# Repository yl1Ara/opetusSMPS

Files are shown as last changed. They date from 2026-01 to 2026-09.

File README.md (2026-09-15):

# opetUSMPS

The active instrument and inversion implementation is `V09_BipolarProto`. The hardware GUI runs on an instrument Raspberry Pi; online inversion is designed to run on a separate analysis computer. See `V09_BipolarProto/deploy/README.md` for installation and update procedures.

## Hardware profiles

- Bipolar systems use the SPI DAC, can scan both voltage polarities, and may enable the Pico inlet valve for Ntot measurements.
- Monopolar Spellman systems use positive scan points only, do not initialize the bipolar SPI DAC, and force Ntot valve measurements off.
- The verified `MPS` monopolar wiring uses the CPC on `/dev/serial0` (GPIO14/15) and Spellman on `/dev/ttyAMA3` (GPIO4/5 with `dtoverlay=uart3`).
- The hardware GUI requires the installed Hauke DMA length before initialization. `MPS` uses the 0.11 m DMA; existing installations retain the 0.28 m default unless configured otherwise. Each scan records its DMA length and radii for inversion.

## Porting older systems

Do not copy old GUI files over a deployment checkout. Commit reviewed changes, update through Git, and preserve settings/logs in the configured state directory so `dmps update` can require a clean fast-forward checkout.

Completed V09 scan CSVs include `scan_complete` and `expected_scan_points`. The inversion viewer rejects interrupted or time-window-truncated scans carrying this metadata, reports what it skipped, and continues processing other valid scans. It also isolates malformed files and individual range inversion failures instead of requiring operators to remove them manually.

Scans collected on a 0.11 m DMA while the controller was still configured for 0.28 m used incorrect classification voltages and should not be treated as correctly sized data. New scan files carry explicit geometry so this mismatch is detectable going forward.

Counting uncertainty is not `sqrt(cpc_count)` because `cpc_count` contains concentration in cm-3, not raw events. V09 converts concentration to effective counts using the configured CPC sample flow and each row's response/counting interval, applies Poisson `sqrt(N)` noise, and linearly propagates one-standard-deviation uncertainty through the active NNLS solution. Saved outputs include per-bin `heatmap_1sigma_*.csv` files and `Ntot_*_1sigma` columns. Verify CPC flow and counting-interval settings when porting this logic to older instruments.

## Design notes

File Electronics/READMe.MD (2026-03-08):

# [Interactive BOM](https://yl1ara.github.io/opetusSMPS/)

# Shopping lists and sites
components per pcb: https://www.digikey.fi/en/mylists/list/RQZPBNJORH

cables and extras: https://www.digikey.fi/en/mylists/list/IEEER25KGX

ACDC 24V 150W: https://www.mouser.fi/ProductDetail/XP-Power/AHM150PS24?qs=w%2Fv1CP2dgqrkrRjfQac7fA%3D%3D

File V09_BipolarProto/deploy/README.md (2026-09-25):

# Customer deployment

This deployment keeps all source files in one SSH-cloned monorepo checkout, but runs only the hardware GUI on an instrument Raspberry Pi:

- Hardware GUI: `gui.py`, systemd `tdmps@USER.service`, localhost port 5006 by default
- Online inversion files remain available for deployment on a separate analysis computer; they are not started on the Pi.

The hardware service restarts after process failures so its web interface remains available. Restarting the web process does not automatically initialize hardware or resume a scan. The server binds only to localhost and accepts only its configured exact websocket origin; wildcards are not used.

The templated hardware unit conflicts with the legacy `tdmps.service`, checks that the configured panel port is free before touching hardware, and rate-limits failed starts. Installation disables inactive legacy service names. If a legacy service is active, `dmps start`, `dmps restart`, and `dmps update` fail closed until it is stopped and disabled.

## SSH deploy key

Create a key on the customer system and leave its passphrase empty for unattended `git fetch`:

```bash
ssh-keygen -t ed25519 -f ~/.ssh/opetus_smps_deploy -C "customer-system-name deploy"
cat ~/.ssh/opetus_smps_deploy.pub
```

Add the public key to the repository as a read-only GitHub deploy key. Configure SSH to use it:

```sshconfig
Host github.com-opetus-smps
    HostName github.com
    User git
    IdentityFile ~/.ssh/opetus_smps_deploy
    IdentitiesOnly yes
```

Verify host identity and access interactively before installation:

```bash
ssh -T git@github.com-opetus-smps
```

## Clone and install

Clone the repository, not `V09_BipolarProto` by itself. The installer verifies this layout:

```text
<repository-root>/V09_BipolarProto
```

```bash
git clone git@github.com-opetus-smps:OWNER/opetusSMPS.git ~/opetusSMPS
cd ~/opetusSMPS/V09_BipolarProto
```

Install `uv` if it is not already available, then install with the system's exact Tailscale MagicDNS name. Origins contain only `host[:port]`, never `https://`, a path, or `*`:

```bash
curl -LsSf https://astral.sh/uv/install.sh | sh
deploy/install-services.sh --origin customer-host.tailnet-name.ts.net
```

Use `--port 5008` when an installation should use a non-default local Panel port. The systemd port guard, Panel launcher, health command, and Tailscale proxy all read the resulting `DMPS_PANEL_PORT` setting.

By default, runtime settings and logs remain under `V09_BipolarProto`. To preserve an existing absolute collection path while running code from a clean clone, pass an existing writable state directory:

```bash
deploy/install-services.sh --origin customer-host.tailnet-name.ts.net --state-dir /home/pi/Desktop/TDMPS
```

The services then load code and dependencies from the Git checkout but retain `settings.json`, `settings_inversion.json`, `logs/`, and viewer state under the state directory.

## Bipolar and monopolar installations

The bipolar installation uses the SPI DAC and may use the Pico inlet valve for Ntot measurements. Keep SPI enabled, select `Bipolar DAC`, and enable the Ntot valve only when that valve is physically installed.

The monopolar installation uses only positive scan points, does not use the bipolar SPI DAC, and never uses the Ntot valve. Disable SPI and enable the CPC and Spellman UARTs in `/boot/firmware/config.txt`:

```ini
## Monopolar MPS
#dtparam=spi=on
enable_uart=1
dtoverlay=disable-bt-pi5
dtoverlay=uart3
```

After rebooting, verify the serial devices before starting the GUI:

```bash
ls -l /dev/serial* /dev/ttyAMA* /dev/ttyS*
```

The verified `MPS` monopolar installation uses `/dev/serial0 -> /dev/ttyS0` on GPIO14/15 for the CPC and `/dev/ttyAMA3` on GPIO4/5 for the Spellman supply. Set `cpc_com_port` to `/dev/serial0`, `spellman_port` to `/dev/ttyAMA3`, `hv_source` to `Monopolar Spellman`, and the Hauke DMA length to `0.11 m` before initializing hardware. Selecting that source forces positive-only scans and disables Ntot controls in the GUI. Other installations retain the `0.28 m` DMA default unless explicitly changed.

After changing overlays, reboot and confirm GPIO4/5 report `TXD3`/`RXD3`. Device aliases can vary with firmware, so verify the actual devices instead of assuming `/dev/serial1` exists.

The installer acquires the instrument maintenance lock and refuses a busy or unverifiable running service before changing dependencies. It creates `.venv`, synchronizes locked application dependencies plus Raspberry Pi hardware dependencies, syntax-checks only the instrument application and hardware modules, installs `dmps`, enables only the hardware service, and verifies both its localhost endpoint and fresh process-matched `health.json` heartbeat. Before Panel starts, a bipolar installation writes calibrated midpoint code `32705` to its DAC; monopolar installations skip that startup action because SPI is disabled. Inversion code is not executed on the instrument.

## Operations and updates

```bash
dmps status
dmps health
dmps system-health
dmps diagnose-reboot
dmps update
```

`dmps update` operates on the complete monorepo. It acquires an exclusive maintenance lock, refuses a dirty tree or non-fast-forward pull, and reads a fresh `health.json` whose PID must match systemd's current process; it never opens a Panel session to determine whether measurement is idle. Measurement, initialization, tuning, and calibration hold shared maintenance leases, so they cannot begin or remain active during an update. If state cannot be verified, the update fails closed. After its final idle check, it stops the hardware service before changing the checkout or environment, runs dependency synchronization and Python syntax checks, installs runtime files, starts the service if it was previously active, and requires the new PID's localhost endpoint and heartbeat to pass. A failed update leaves the service stopped rather than running mixed old and new files. Do not copy tracked source files into an installed checkout: publish changes to GitHub, keep runtime files under the configured state directory, and use `dmps update` so the checkout remains clean.

Stop a measurement in the GUI and confirm it is idle before updating. Do not schedule `dmps update` from cron or a systemd timer. Do not manually run a second hardware GUI beside `tdmps@USER.service`.

Service logs are available with `dmps log`. Installation overrides Raspberry Pi OS's volatile-journal default and retains up to 200 MB or three months of system journals across reboots. The independent `tdmps-health-log@USER.service` fsyncs CPU temperature and frequency, Raspberry Pi throttling history, uptime, load, memory, boot identity, and Tailscale version/state every minute under `logs/system/`; `dmps system-health` shows its latest records. After an unexplained reboot or outage, `dmps diagnose-reboot` prints those records alongside boot history, watchdog policy, current Pi throttling flags, current and previous boot power/reset kernel messages, and retained previous-boot TDMPS service logs. `dmps events` shows the latest persistent JSONL runtime events from `logs/runtime/`, including panel sessions, measurement transitions, one-minute hardware heartbeats, scan QC, failures, and shutdown results. The existing `tdmps@USER.service` name is retained for compatibility.

Stopping the service first invokes the application's idempotent safe shutdown. After the process exits, `ExecStopPost` independently attempts to command the inlet valve off, both HV outputs safe, and the blower DAC to zero, regardless of the currently saved profile. Missing hardware is reported but does not prevent the remaining safing attempts. This second layer never runs alongside the application.

## Tailscale exposure

The hardware service remains localhost-only. To expose it to the tailnet, install and authenticate Tailscale, then enable the supplied proxy unit:

```bash
sudo tailscale up
sudo systemctl enable --now "tdmps-serve@$(whoami).service"
tailscale serve status
dmps url
```

The route is:

```text
https://customer-host.tailnet-name.ts.net/gui
```

Use Tailscale ACLs/grants to limit customer access. Do not open the local Panel port in the host firewall and do not bind Panel to `0.0.0.0`.

## One-time migration from the copied TDMPS directory

Older systems may have `/home/pi/Desktop/TDMPS` as a standalone, dirty checkout. Do not run `git pull` there and do not delete it. Stop measurement and zero HV in the GUI first, then create the clean monorepo clone described above. Preserve local state before replacing the legacy service:

```bash
mkdir -p ~/opetusSMPS/V09_BipolarProto/logs
rsync -a ~/Desktop/TDMPS/logs/ ~/opetusSMPS/V09_BipolarProto/logs/
cp ~/Desktop/TDMPS/settings.json ~/opetusSMPS/V09_BipolarProto/settings.json
cp ~/Desktop/TDMPS/settings_inversion.json ~/opetusSMPS/V09_BipolarProto/settings_inversion.json
sudo systemctl disable --now tdmps.service
cd ~/opetusSMPS/V09_BipolarProto
deploy/install-services.sh --origin "$(tailscale status --json | python3 -c 'import json,sys; print(json.load(sys.stdin)["Self"]["DNSName"].rstrip("."))')"
```

The installer intentionally refuses to proceed while the legacy service is active, preventing two hardware controllers from binding the same port or opening the same devices. Keep the old directory as a backup until the new main GUI, online viewer, settings, and historical logs have been verified.

The repository no longer tracks Python bytecode. Commit the accompanying `__pycache__` deletions and `.gitignore` update before cloning customer systems; otherwise imported bytecode can make future pulls dirty.

## Online inversion computer

Run inversion on a separate analysis computer, not on the instrument Pi. The repository includes `online_inversion_viewer.py`, `DMPS_inversion_gui/`, and `run_online_inversion_viewer.sh`. On the analysis computer:

```bash
cd ~/opetusSMPS/V09_BipolarProto
./run_online_inversion_viewer.sh
```

Set `ONLINE_VIEWER_ORIGIN=analysis-host.example:5007` when accessing it through another exact hostname. The launcher binds only to localhost by default; use a separate authenticated proxy or SSH forwarding for remote access.

On the CSC analysis host, install the tracked service helper after cloning the repository:

```bash
cd /home/ubuntu/opetusSMPS/V09_BipolarProto
sudo install -o root -g root -m 0755 deploy/inversion /usr/local/bin/inversion
sudo install -o root -g root -m 0644 deploy/inversion-completion.bash /etc/bash_completion.d/inversion
```

The production defaults are service `opetus-panel.service`, checkout
`/home/ubuntu/opetusSMPS/V09_BipolarProto`, and local health URL
`http://127.0.0.1:5008/online_inversion_viewer`. They can be overridden with
`INVERSION_SERVICE`, `INVERSION_APP_DIR`, and `INVERSION_HEALTH_URL`.

Use `inversion status`, `inversion health`, and `inversion tail` for routine
operation. `inversion update` refuses a dirty, detached, locally advanced, or
diverged checkout. It fetches and fast-forwards only from `origin/main`, runs a
locked dependency sync and Python/shell syntax checks, refreshes the helper,
and health-checks the restarted viewer. A stopped viewer remains stopped.

There is no reliable external signal for all per-session inversion jobs. When
the viewer is active, update therefore requires an interactive `UPDATE`
confirmation after all users have been notified and all jobs have finished.
Do not automate this command. It stops the viewer before changing source or
dependencies. A failed validation leaves it stopped; correct the problem,
rerun `inversion update`, then use `inversion start`. The Pi-specific
measurement-idle check does not protect online inversion work.

### CSC instrument data pull

The CSC `sync-dmps.timer` runs `/usr/local/bin/sync-dmps` as `ubuntu` every
30 minutes. The tracked script pulls `/home/pi/Desktop/TDMPS/logs/` from
`pi@varjo-dmps` into `/home/ubuntu/dmps/logs/` without deleting CSC files.
It uses `/home/ubuntu/.ssh/raspberrypi_sync` and the Pi's already-verified
`raspberrypi` SSH host-key entry (via `HostKeyAlias`). To install and check it
on CSC:

```bash
cd ~/opetusSMPS/V09_BipolarProto
sudo install -o root -g root -m 0755 deploy/sync-dmps /usr/local/bin/sync-dmps
sync-dmps --dry-run
sudo systemctl start sync-dmps.service
systemctl status sync-dmps.service --no-pager
systemctl list-timers sync-dmps.timer --no-pager
```

The first successful run may copy a backlog of scans. `journalctl -u
sync-dmps.service` shows the transfer summary or an SSH/rsync error.

The separate SMEAR III monopolar Pi (`pi@mps`) writes to
`/home/pi/opetusSMPS/V09_BipolarProto/logs/`. Its data belongs under
`/home/ubuntu/mps/logs/` on CSC, not in the bipolar `dmps` tree. Once CSC
can SSH to `pi@mps` without an interactive Tailscale check, install and
enable the independent MPS job:

```bash
cd ~/opetusSMPS/V09_BipolarProto
sudo install -o root -g root -m 0755 deploy/sync-mps /usr/local/bin/sync-mps
sudo install -o root -g root -m 0644 deploy/sync-mps.service /etc/systemd/system/sync-mps.service
sudo install -o root -g root -m 0644 deploy/sync-mps.timer /etc/systemd/system/sync-mps.timer
sync-mps --dry-run
sudo systemctl daemon-reload
sudo systemctl enable --now sync-mps.timer
sudo systemctl start sync-mps.service
systemctl status sync-mps.service --no-pager
```

If CSC gets a Tailscale SSH web-approval prompt, arrange noninteractive
access for this host in the tailnet policy before enabling the timer; an
interactive approval alone will not make unattended sync reliable.

### University SMB data through the desktop

The university SMB share is mounted on the local desktop using eduVPN's
**Split-tunnel** profile. CSC does not need eduVPN: a local user timer stages
only `*.scan` from UFSMPS 2026 and `*.scan`/`*.sum` from SMPS dated June 2026
onward, then pushes completed files to CSC over the existing SSH connection.
The local stage is `~/.local/share/opetusSMPS/university/2026/{ufsmps,smps}`;
CSC receives `/home/ubuntu/university/2026/{ufsmps,smps}`. No SMB login or
VPN configuration is copied to CSC, and no source or CSC files are deleted.

On the desktop, while logged in with eduVPN connected and `h527` mounted in
the file manager:

```bash
cd ~/Desktop/Projects/opetusSMPS/V09_BipolarProto
install -m 0755 deploy/sync-university-local ~/.local/bin/sync-university-local
install -m 0644 deploy/sync-university-local.service ~/.config/systemd/user/
install -m 0644 deploy/sync-university-local.timer ~/.config/systemd/user/
sync-university-local --dry-run
systemctl --user daemon-reload
systemctl --user enable --now sync-university-local.timer
systemctl --user start --no-block sync-university-local.service
```

The first run stages several gigabytes and may take a while. The timer retries
every 30 minutes while the desktop's user session is running; when eduVPN or
the SMB mount is unavailable it skips SMB and still sends previously staged
files to CSC. Check `systemctl --user status sync-university-local.service`
and `journalctl --user -u sync-university-local.service` for the outcome.
The script checks that the university server's route uses `eduVPN`; it does
not change the default route or connect/disconnect any VPN.

### Inverting the synced scans on CSC

The online viewer loads independent **Bipolar Pi**, **Monopolar Pi**,
**SMEAR III UFSMPS**, and **SMEAR III SMPS** instrument tabs on demand. Each
tab has its own inversion controls and result. The **Comparison** tab plots
their independently inverted heatmaps on the same color scale and compares
measured-range N only over their common diameter interval (when one exists).
Each instrument tab and **My Explorer** saves its settings under
`~/.local/share/opetusSMPS/inversion-settings/` on the analysis host. The
global tab continues to use `settings_inversion.json`. These files survive
viewer restarts and `inversion update`; the first load of an instrument tab
imports its latest legacy per-session settings if available. Keep the settings
directory when replacing the Git checkout. The **Comparison** tab also saves
its model, polarity, and color-scale maximum in this directory.

Use **Refresh comparison** after new inversions finish; tabs and results are
personal to that browser session. The **Scan source** selector within each
tab also supports a custom folder. Select a small number of days before
running inversion (university `.scan` files contain many scans per day); the
university tabs start at one day. The SMEAR III SMPS `.sum`
reference folder defaults to `/home/ubuntu/university/2026/smps` on CSC;
it can be edited in the diagnostics controls for the median and ratio plots.
Only `.scan` files enter the inversion; `.sum` files are comparison data.
Exports from UFSMPS, SMPS, and the monopolar Pi are kept in separate
subdirectories under the configured save folder. Check each instrument's
flows, CPC, size cutoff, timing correction, and inlet/tube-loss settings
before interpreting or comparing inverted distributions.

In an instrument's **Inversion** tab, choose Rectangle or Freehand and drag
across heatmap cells to inspect a region. The **Saved ROIs** tab shows the
selected distributions and, for at least four scans spanning 15 minutes, a
descriptive D50-vs-time slope. On **Global Live**, selection appears in its
**Selected ROI** tab instead. The growth status above each inversion heatmap
explains when automatic tracks were rejected; marginal tracks show points
without a fitted line. The **Growth Signal** tab plots full per-size
background-subtracted enhancement and a separate view of the component the
tracker selected. Its color scales are independent; positions on the raw
inversion heatmap are markers, not a raw-peak fit. A moving D50 without a
moving component peak is marked marginal, since it may reflect broadening.
The main 72-hour SMEAR median pairs scans within 15 minutes before comparing
distributions, while Difference Diagnostics uses paired scans from the last
three hours.

For a consistent clock comparison, set **Our → SMEAR comparison time shift
(s)** in the instrument tab's Diagnostics controls. For example, `-130`
places our comparison points 130 seconds earlier. This is separate from
**SMPS system settling** and does not edit the scan timestamps or the
standalone inversion heatmap. Click **Apply time shift to plots** to refresh
the existing inversion's comparison panels without recalculating its transfer
matrix. The SMPS Timing tab then searches for a best
*additional* offset; the cross-instrument Comparison tab uses each source's
configured display offset as well (click **Refresh comparison** there after
changing an instrument's shift).

The **Zn/Zp for inversion** selector offers configured Zn/Zp, the processed
paired-polarity scan estimate for Gunn-Woessner, or an explicit experimental
option applying that estimate to Fuchs too. The per-scan ratio source and
value are recorded in heatmap-condition exports. A monopolar scan has no
paired-polarity estimate and falls back to configured Zn/Zp; Wiedensohler's
fixed charge fractions do not use this control.

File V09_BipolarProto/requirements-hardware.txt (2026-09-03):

GP8XXX-IIC==0.0.4
gpiozero==2.0.1
pyserial==3.5
rpi-lgpio==0.6
sensirion_i2c_driver==1.0.2
sensirion_i2c_sdp==0.1.1
simple-pid==2.0.1
smbus2==0.6.1
spidev==3.8

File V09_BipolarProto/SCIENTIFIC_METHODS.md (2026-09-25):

# Scientific analysis methods

The online inversion viewer includes measured-range particle moments,
sulfuric-acid condensation sink, neutral Brownian coagulation sink,
lognormal modal fitting, and an experimental maximum-cross-correlation (MCC)
growth-rate cross-check.

## Scope and assumptions

- Input distributions are `dN/dlog10Dp` in `cm-3`; diameter centers are in nm.
- Number, surface, volume, CS, and CoagS use only measured finite bins. They do
  not extrapolate unmeasured particle sizes.
- Surface and volume assume spherical particles.
- CS assumes sulfuric acid condensing in air with unit accommodation.
- CoagS uses a neutral Fuchs transition-regime Brownian kernel. It excludes
  electrostatic enhancement and uses the configured spherical-particle density.
- Temperature and pressure can be matched per scan from an optional ambient CSV
  containing `time`, `temperature_k` or `temperature_c`, and `pressure_pa` or
  `pressure_hpa`. Observations outside the configured nearest-match tolerance
  fall back explicitly to the configured inversion conditions.
- Positive/negative inversion labels are DMA voltage signs; selected particle
  charge has the opposite sign.
- The ion-mobility ratio is always `Zn/Zp`: negative-ion mobility divided by
  positive-ion mobility. The nominal default is 1.60/1.35.
- A scan-derived `Zn/Zp` uses the Gunn-Woessner square-root relation and is
  corrected by the configured `Np/Nn`. The processed estimate applies the
  optional additive operator offset, candidate bounds, and temporal step
  limiter; the offset defaults to zero for new settings. The legacy mode uses
  it for Gunn-Woessner only and uses the configured ratio for Fuchs. An
  explicit experimental option can also feed that Gunn-Woessner-derived
  estimate to Fuchs; it is not an independent ion measurement. Scans without
  a valid estimate (including monopolar scans without both voltage signs)
  fall back to the configured ratio. Wiedensohler uses fixed charging
  fractions independent of the selected ion-mobility ratio.
- The optional polarity-consistency diagnostic pairs positive- and
  negative-voltage columns by scan ID and compares only common measured support,
  defaulting to 20-70 nm. Under the singly charged Gunn-Woessner relation it
  reports `effective Zn/Zp = used Zn/Zp * sqrt(median(Npositive/Nnegative))`
  and evaluates the corresponding robust log-mismatch over a candidate-ratio
  grid. This is a model-dependent consistency estimate, not an independent ion
  mobility measurement. It can absorb `Np/Nn`, aerosol evolution between
  polarity scans, CPC response and efficiency, DMA asymmetry, transport losses,
  multiply charged particles, and other inversion errors. Results are therefore
  never applied automatically. Per-CPC summaries and correction-mode provenance
  are exported so instrument-dependent estimates can be identified. The
  candidate objective first takes a median over diameter within each pair and
  then a median over equally weighted pairs. An optimum at the configured
  candidate-range boundary is explicitly marked as bound-limited.
- The experimental Fuchs-type solver is a corrected Chen-derived limiting-
  sphere implementation with adaptive charge-state detailed balance. It is not
  yet claimed to reproduce the complete Hoppel-Frick (1986) three-body model;
  like-sign attachment can truncate to zero below about 20 nm.
- A modal component's `area_cm3` is the fitted full-lognormal integral. The UI
  reports `fit_range_area_cm3` integrated only over measured support to avoid
  presenting extrapolated modal tails or internal gaps as measured concentration.
- MCC is an experimental distinct-estimator cross-check on the same inversion data. It is disabled by default
  and does not accept or reject the primary geometric growth tracks.
- Automatic growth tracks are heuristic and depend on measured diameter
  coverage, coherent enhancement, temporal continuity, and fit quality. Sparse
  diameter grids use a two-bin coherence requirement; marginal tracks appear
  as observed points without a fitted overlay. A moving D50 with a stationary
  peak in its selected component is classified as marginal (possible
  broadening rather than particle growth). Growth tracks follow a
  background-subtracted signal and need not coincide with the brightest bin
  of the raw inversion. The raw heatmap marks candidate positions; the
  separate Growth Signal plot shows full enhancement and the subset of bins
  selected for the track, with independent color scales. A user-selected
  heatmap ROI also reports a descriptive D50 slope when at least
  four scans span 15 minutes; it is not an independent growth measurement.
- The main SMEAR III distribution comparison uses only scans paired within
  15 minutes during the latest 72 hours, with the SMEAR distribution interpolated
  onto the inversion's measured diameter bins. Difference Diagnostics applies
  the same matching to the latest three hours; the two periods can still have
  different aerosol populations.
- The optional **our-to-SMEAR comparison time shift** applies to the Pi's
  timestamps only in SMEAR comparison plots and nearest-scan matching. Negative
  values move our comparison clock earlier. It never changes recorded scan
  times, standalone inversion heatmaps, SMPS settling time, or the transfer
  model. The SMPS timing diagnostic then reports the *additional* best shift
  beyond the configured value; a best shift is a matching diagnostic, not an
  independent clock measurement.
- Particle formation diagnostics report a three-term apparent budget in
  `cm-3 s-1`:
  accumulation `dN/dt`, growth outflux `GR*N/(d2-d1)`, and neutral Brownian
  restricted neutral Brownian coagulation sink approximation. It omits
  smaller-collector interactions and coagulation-product gains. Apparent `J` is reported only
  where all three terms are finite; it does not include dilution, deposition,
  transport, or charged-particle terms. Growth-slope p10-p90 propagation is a
  sensitivity range, not a confidence interval. Marginal growth candidates
  are excluded from the growth-outflux term.
- The experimental Fuchs-type path uses configured positive-ion mobility and
  the selected `Zn/Zp` to set negative-ion mobility at the scan conditions.
  Pressure is validated and recorded but does not independently rescale the
  charging fractions.
- The SMEAR III UFSMPS `.scan` importer currently uses the last of its two
  CPC concentration/count columns (TSI3756), not the first UFCPC channel
  (TSI3750). CPC efficiency for these models is not calibrated in the current
  loss function. UFSMPS measured aerosol flow can be about 0.05 L/min, while
  the inversion uses the selected run's configured flow and tube losses;
  setting the source folder alone does not validate those inputs.

## References

- Kulmala et al. (2012), Measurement of the nucleation of atmospheric aerosol
  particles, Nature Protocols 7, 1651-1667.
  https://doi.org/10.1038/nprot.2012.091
- Fuller et al. (1966), A new method for prediction of binary gas-phase
  diffusion coefficients. https://doi.org/10.1021/ie50677a007
- Sutugin and Fuchs (1971), transition-regime correction.
  https://doi.org/10.1016/0021-8502(71)90061-9
- Hinds (1999), Aerosol Technology, 2nd edition, Brownian diffusion and
  transition-regime coagulation.
- Lampilahti et al. (2025), maximum-cross-correlation growth-rate method.
  https://doi.org/10.5194/ar-3-637-2025
- Fuchs (1963), stationary aerosol charge distribution in a bipolar ionic
  atmosphere. https://doi.org/10.1007/BF01993343
- Hoppel and Frick (1986), ion-aerosol attachment coefficients and steady-state
  bipolar charge distributions. https://doi.org/10.1080/02786828608959073
- Wiedensohler (1988), polynomial approximation of bipolar submicron charge
  distributions. https://doi.org/10.1016/0021-8502(88)90278-9

The interaction and analysis design was informed by the MIT-licensed
`aerosol-functions` and `aerosol-studio` projects. See
`THIRD_PARTY_NOTICES.md`.

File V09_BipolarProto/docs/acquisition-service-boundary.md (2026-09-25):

# Acquisition Service Boundary

The measurement runtime must not be owned by a browser session. Panel may render controls, plots, snapshots, and status, but opening or closing a browser tab must never start, stop, reset, or safe the instrument.

## Runtime Ownership

- One acquisition service process owns CPC, DMA, blower, valve, flowmeter, HV, scan state, active data buffers, and output files.
- The service starts and stops under systemd, not under a Panel/Bokeh session lifecycle.
- Shutdown and hardware safing happen only on explicit service shutdown, fatal runtime failure, or explicit stop/safe command.
- The UI polls or subscribes to runtime snapshots and submits commands to the service.

The current GUI already has useful concepts to preserve: `runtime_snapshot()`, `publish_runtime_snapshot()`, and command forwarding. The unsafe part to remove during the refactor is the owner Panel document being the hardware owner.

## Shared Control Model

Every authorized viewer may access the same control page. The UI is shared: all viewers see the same current state, same active scan, same settings, same latest data, and same command history.

To avoid conflicting edits:

- Commands are serialized by the acquisition service.
- Each command carries a `requester_id`, `requester_label`, `command_id`, timestamp, command type, and payload.
- A short control lease marks the currently active controller.
- The same controller can continue making changes while the lease is active.
- Another viewer can take control after the lease expires or through an explicit takeover action.
- Measurement-critical commands are validated by the service, not only by disabled UI widgets.

The lease is a coordination tool, not authentication. Network access control still belongs to the lab network, Tailscale ACLs, or an authenticated reverse proxy.

## Command Rules

- `start_scan`: accepted only when the runtime is initialized, idle, and settings validate.
- `stop_scan`: accepted while running or stopping; it remains available even when another viewer has the lease.
- `setting`: accepted only while idle; changes during an active scan are staged for the next scan or rejected explicitly.
- `initialize`: accepted only while idle.
- `manual_hv`: accepted only while idle or in a dedicated maintenance mode.
- `snapshot`: always read-only.

The service response should include whether the command was accepted, rejected, or queued, plus the reason. The UI should show this response to every connected viewer.

## Snapshot Content

Snapshots should include at least:

- Stable instrument ID.
- Runtime process ID/session ID.
- Runtime state: `starting`, `idle`, `running`, `stopping`, `error`, or `shutdown`.
- Whether a scan is active.
- Current phase/progress/status text.
- Active controller label and lease expiry.
- Last accepted command and requester.
- Current settings and which ones are editable.
- Latest CPC, flow, HV, aerosol, Ntot, table, QC, and live plot source data.
- Last completed scan metadata and file path.
- Last runtime error.

## Refactor Steps

1. Keep the current Panel UI and introduce a runtime client object behind existing callbacks.
2. Move command validation into service-side code using `DmpsControl.runtime_contract`.
3. Move hardware initialization and scan threads into a service object that can run without a Panel document.
4. Replace `pn.state.cache` owner/follower hardware ownership with service snapshots and command calls.
5. Remove browser-session shutdown of hardware. Session close should only remove that browser's UI callbacks.
6. Add an HTTP/WebSocket transport only after the in-process service boundary is stable.

This preserves the workflow students need: everyone sees live progress, snapshots, starts, stops, and status, while the measurement itself is protected from browser reconnects and accidental concurrent edits.

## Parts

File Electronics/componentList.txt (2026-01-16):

components: https://www.digikey.fi/en/mylists/list/RQZPBNJORH
cables and extra: https://www.digikey.fi/en/mylists/list/IEEER25KGX
ACDC 24V 150W: https://www.mouser.fi/ProductDetail/XP-Power/AHM150PS24?qs=w%2Fv1CP2dgqrkrRjfQac7fA%3D%3D

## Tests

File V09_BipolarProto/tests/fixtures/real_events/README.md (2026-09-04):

# Anonymized real-event fixtures

Real-event regressions are opt-in because no approved historical event is
currently stored in the repository. Add matching `EVENT.npz` and `EVENT.json`
files here after checking data-release permission.

The NPZ file must contain:

- `elapsed_minutes`: strictly increasing one-dimensional offsets.
- `diameter_nm`: strictly increasing one-dimensional bin centers.
- `concentration_cm3`: `dN/dlog10Dp`, shaped `(diameter, time)`.

The JSON sidecar must contain:

- `fixture_version`: currently `1`.
- `event_id`: a non-identifying stable name.
- `time_origin`: a synthetic ISO-8601 timestamp used only to reconstruct cadence.
- `polarity`: `positive` or `negative` DMA-voltage sign.
- `anonymization`: statement covering shifted time, removed location/instrument IDs,
  and whether concentrations were scaled.
- `expected`: accepted ranges for event count, growth rate, onset, modal tracks,
  and integrated concentration. Ranges must come from a reviewed baseline, not
  from the code under test in the same run.

Use `tests.real_event_fixtures.load_real_event_fixture` in regression tests.
Never include raw filenames, absolute timestamps, coordinates, operator names,
or acquisition-session identifiers.

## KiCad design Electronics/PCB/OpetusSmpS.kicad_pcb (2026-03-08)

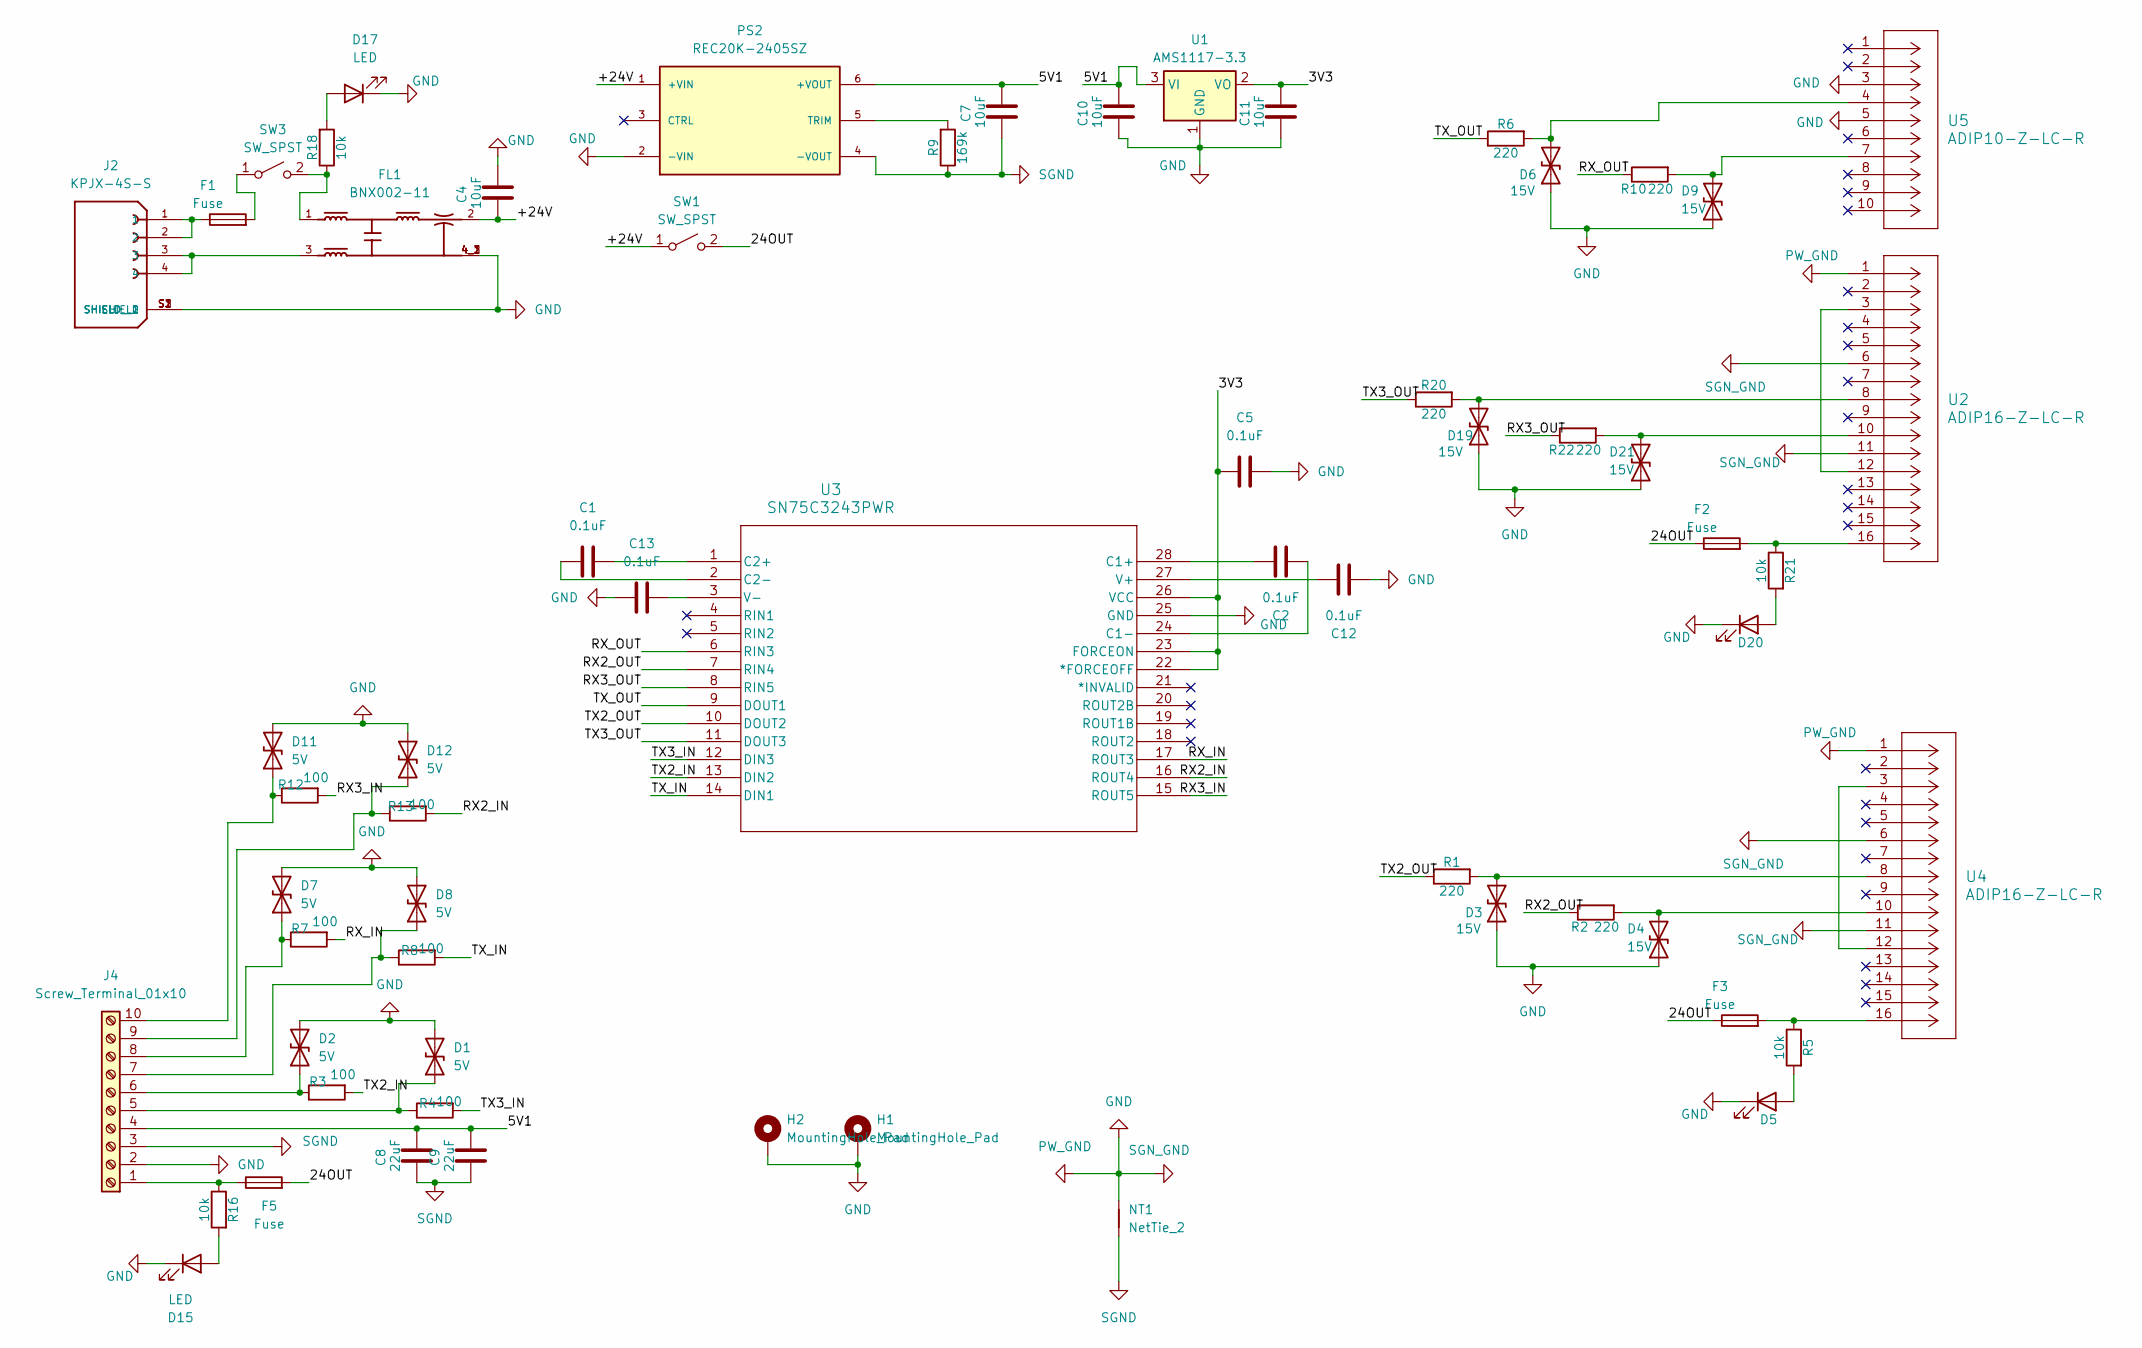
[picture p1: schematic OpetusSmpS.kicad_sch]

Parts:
C1, C2, C5, C12, C13: 0.1uF; C_0603_1608Metric_Pad1.08x0.95mm_HandSolder
C4, C7, C10, C11: 10uF; C_0603_1608Metric_Pad1.08x0.95mm_HandSolder
C8, C9: 22uF; C_0603_1608Metric_Pad1.08x0.95mm_HandSolder
D1, D2, D7, D8, D11, D12: 5V; D_SMA
D3, D4, D6, D9, D19, D21: 15V; D_SMB_Handsoldering
D5, D15, D17, D20: LED; PinHeader_1x02_P2.54mm_Vertical
F1: Fuse; Fuseholder_Cylinder-5x20mm_Schurter_0031_8201_Horizontal_Op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
F2, F3, F5: Fuse; FUS_RHEF100_TYCO_TYC
FL1: BNX002-11; FIL_BNX002-11; PARTREV N/A
H1, H2: MountingHole_Pad; MountingHole_4mm_Pad_Via
J2: KPJX-4S-S; KYCON_KPJX-4S-S; PARTREV A15
J4: Screw_Terminal_01x10; TerminalBlock_Phoenix_MKDS-1,5-10_1x10_P5.00mm_Horizontal
NT1: NetTie_2; NetTie-2_THT_Pad0.3mm
PS2: REC20K-2405SZ; CONV_REC20K-2405SZ; PARTREV PRELIMINARY
R1, R2, R6, R10, R20, R22: 220; R_1206_3216Metric_Pad1.30x1.75mm_HandSolder
R3, R4, R7, R8, R12, R13: 100; R_1206_3216Metric_Pad1.30x1.75mm_HandSolder
R5, R16, R18, R21: 10k; R_0805_2012Metric_Pad1.20x1.40mm_HandSolder
R9: 169k; R_0805_2012Metric_Pad1.20x1.40mm_HandSolder
SW1, SW3: SW_SPST; SolderWire-0.1sqmm_1x02_P3.6mm_D0.4mm_OD1mm
U1: AMS1117-3.3; SOT-223-3_TabPin2
U2, U4: ADIP16-Z-LC-R; CON16_300_DIP_AM_ASM
U3: SN75C3243PWR; PW28
U5: ADIP10-Z-LC-R; CON10_300_DIP_AM_ASM

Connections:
/3V3: C5.1, C11.2, U1.2 (VO), U3.22 (*FORCEOFF), U3.23 (FORCEON), U3.26 (VCC)
/5V1: C7.2, C8.2, C9.2, C10.2, J4.4, PS2.6 (+VOUT), U1.3 (VI)
/24OUT: F2.1, F3.1, F5.2, SW1.2 (B)
/+24V: C4.1, FL1.2, PS2.1 (+VIN), SW1.1 (A)
/RX2_IN: R13.2, U3.16 (ROUT4)
/RX2_OUT: R2.1, U3.7 (RIN4)
/RX3_IN: R12.2, U3.15 (ROUT5)
/RX3_OUT: R22.1, U3.8 (RIN5)
/RX_IN: R7.2, U3.17 (ROUT3)
/RX_OUT: R10.1, U3.6 (RIN3)
/TX2_IN: R3.2, U3.13 (DIN2)
/TX2_OUT: R1.1, U3.10 (DOUT2)
/TX3_IN: R4.2, U3.12 (DIN3)
/TX3_OUT: R20.1, U3.11 (DOUT3)
/TX_IN: R8.2, U3.14 (DIN1)
/TX_OUT: R6.1, U3.9 (DOUT1)
GND: C4.2, C5.2, C10.1, C11.1, C12.2, C13.2, D1.2 (A2), D2.2 (A2), D3.1 (A1), D4.1 (A1), D5.1 (K), D6.1 (A1), D7.2 (A2), D8.2 (A2), D9.1 (A1), D11.2 (A2), D12.2 (A2), D15.1 (K), D17.1 (K), D19.1 (A1), D20.1 (K), D21.1 (A1), FL1.4_1, FL1.4_2, FL1.4_3, H1.1, H2.1, J2.S1 (SHIELD), J2.S2 (SHIELD__1), J2.S3 (SHIELD__2), J4.2, NT1.2, PS2.2 (-VIN), U1.1 (GND), U2.1, U2.6, U2.11, U3.25 (GND), U4.1, U4.6, U4.11, U5.3, U5.5
unnamed: D1.1 (A1), J4.5, R4.1
unnamed: D2.1 (A1), J4.6, R3.1
unnamed: D3.2 (A2), R1.2, U4.8
unnamed: D4.2 (A2), R2.2, U4.10
unnamed: D5.2 (A), R5.2
unnamed: D6.2 (A2), R6.2, U5.4
unnamed: D7.1 (A1), J4.8, R7.1
unnamed: D8.1 (A1), J4.7, R8.1
unnamed: D9.2 (A2), R10.2, U5.7
unnamed: D11.1 (A1), J4.10, R12.1
unnamed: D12.1 (A1), J4.9, R13.1
unnamed: D15.2 (A), R16.2
unnamed: D17.2 (A), R18.2
unnamed: D19.2 (A2), R20.2, U2.8
unnamed: D20.2 (A), R21.2
unnamed: D21.2 (A2), R22.2, U2.10
unnamed: F1.1, J2.1, J2.2
unnamed: F2.2, R21.1, U2.16
unnamed: F3.2, R5.1, U4.16
unnamed: FL1.3, J2.3, J2.4
unnamed: F5.1, J4.1, R16.1
unnamed: PS2.5 (TRIM), R9.2
unnamed: F1.2, SW3.1 (A)
unnamed: FL1.1, R18.1, SW3.2 (B)
unnamed: U2.3, U2.12
unnamed: C2.1, U3.28 (C1+)
unnamed: C2.2, U3.24 (C1-)
unnamed: C1.2, U3.1 (C2+)
unnamed: C1.1, U3.2 (C2-)
unnamed: C12.1, U3.27 (V+)
unnamed: C13.1, U3.3 (V-)
unnamed: U4.3, U4.12
SGND: C7.1, C8.1, C9.1, J4.3, NT1.1, PS2.4 (-VOUT), R9.1

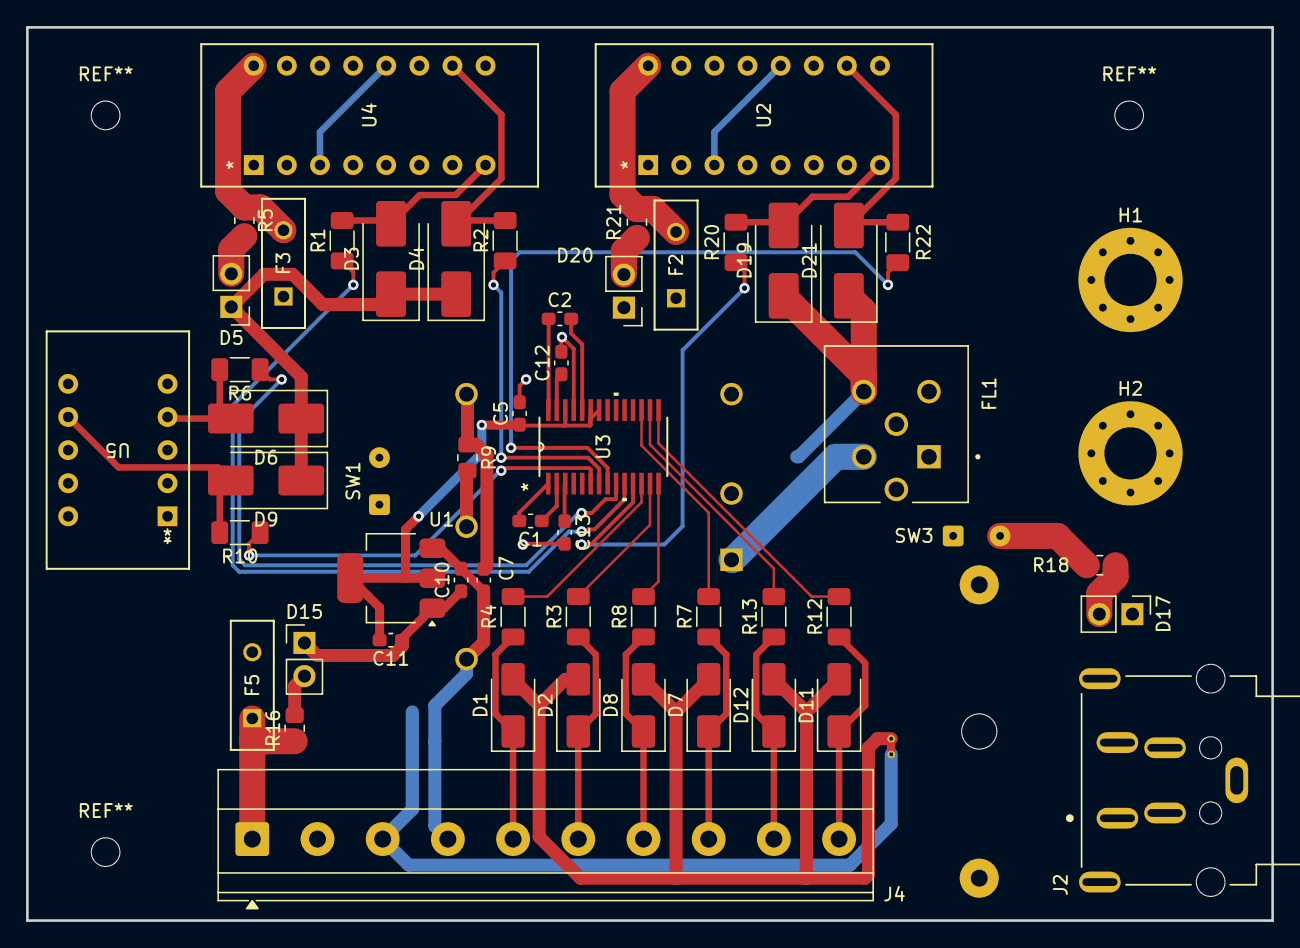
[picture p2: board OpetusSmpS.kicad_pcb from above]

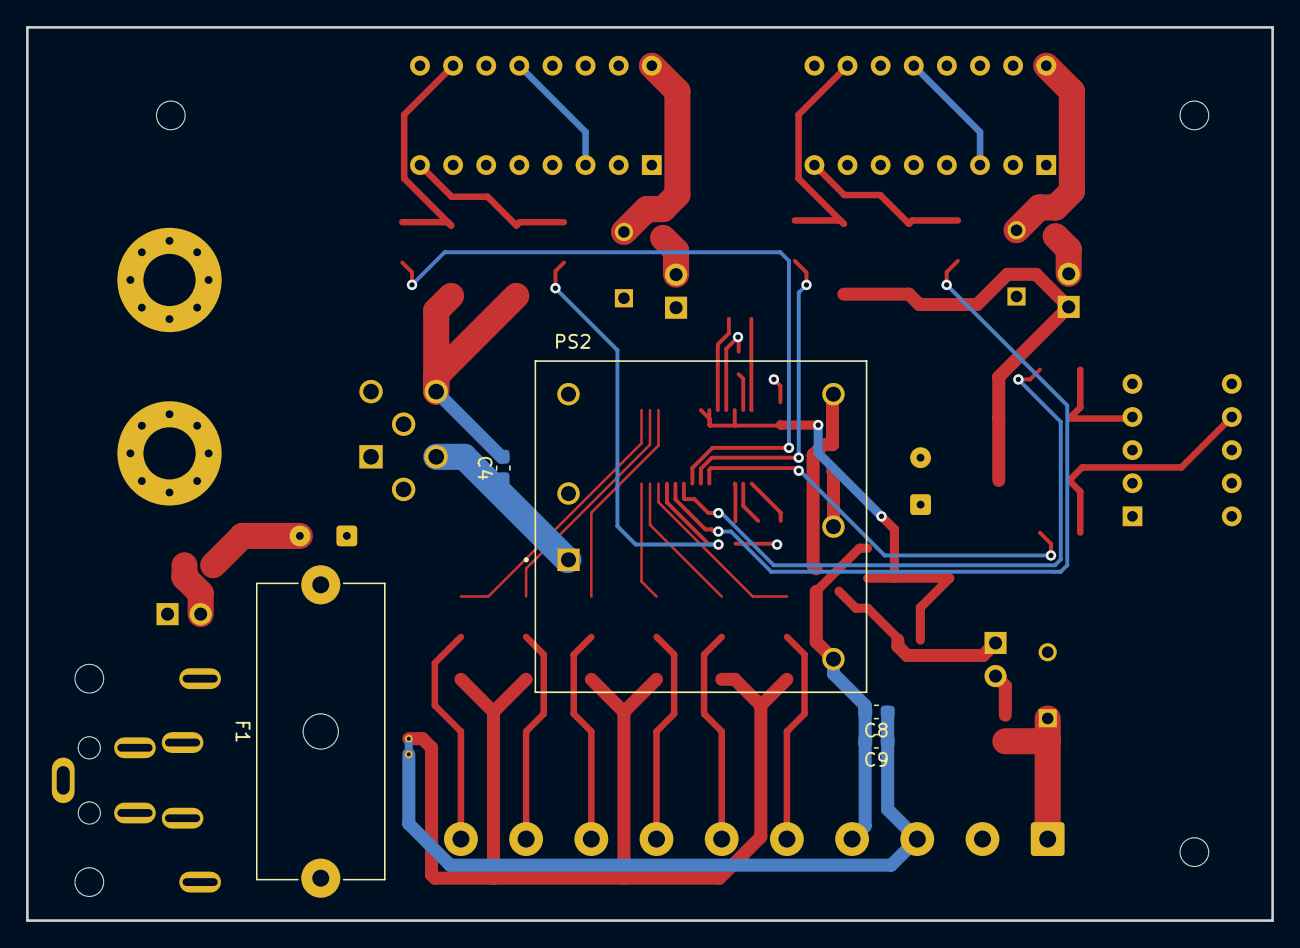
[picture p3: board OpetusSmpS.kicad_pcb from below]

Board: 4 copper layers, 95.5 x 68.5 mm, 62 parts (5 on the bottom side), 50 nets.

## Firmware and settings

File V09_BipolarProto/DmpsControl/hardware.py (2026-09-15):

from GP8XXX_IIC import GP8403
import serial
import time
import smbus2
import threading
from smbus2 import i2c_msg
from gpiozero import OutputDevice, PWMOutputDevice

class CPC:
    def __init__(self, port, CPC_type="3010"):
        self.type = CPC_type
        self.lock = threading.Lock()
        self.terminator = b"\r"
        if self.type == "3010":
            self.ser = serial.Serial(
                port=port,
                baudrate=9600,
                bytesize=serial.SEVENBITS,
                parity=serial.PARITY_EVEN,
                stopbits=serial.STOPBITS_ONE,
                timeout=1,
                write_timeout=0.2,
            )
            self.concentration_command = "RD"
        elif self.type == "3771":
            self.ser = serial.Serial(
                port=port,
                baudrate=115200,
                bytesize=serial.EIGHTBITS,
                parity=serial.PARITY_NONE,
                stopbits=serial.STOPBITS_ONE,
                timeout=1,
                write_timeout=0.2,
            )
            self.concentration_command = "RD"
        elif self.type == "HY09":
            self.ser = serial.Serial(
                port=port,
                baudrate=115200,
                bytesize=serial.EIGHTBITS,
                parity=serial.PARITY_EVEN,
                stopbits=serial.STOPBITS_ONE,
                timeout=1,
                write_timeout=0.2,
            )
            self.concentration_command = "RB"
        else:
            raise ValueError(f"Unsupported CPC type: {CPC_type}")

    def _read_record(self):
        return self.ser.read_until(self.terminator).decode("ascii", errors="replace").strip()

    def read_instrument(self):
        response = self.query(self.concentration_command)
        return response if response else "nan"

    def query(self, command, read_lines=1, reset_input=True):
        cmd = str(command).strip()
        if not cmd:
            raise ValueError("CPC command is empty")

        with self.lock:
            if reset_input:
                self.ser.reset_input_buffer()
            payload = cmd.encode("ascii", errors="replace") + self.terminator
            self.ser.write(payload)
            self.ser.flush()

            lines = []
            echo_skipped = False
            while len(lines) < max(1, int(read_lines)):
                line = self._read_record()
                if not echo_skipped and line.casefold() == cmd.casefold():
                    echo_skipped = True
                    continue
                if line.upper() in {"ERROR", "SWITCH ERROR"}:
                    raise RuntimeError(f"CPC rejected {cmd}: {line}")
                lines.append(line)
                if not line:
                    break

        return "\n".join(lines).strip()

    def close(self):
        with self.lock:
            if self.ser is not None and self.ser.is_open:
                self.ser.close()


class HaukeDMA:
    def __init__(self, length_m=0.28):
        if float(length_m) <= 0:
            raise ValueError("DMA length must be positive")
        self.r1 = 0.025
        self.r2 = 0.033
        self.L = float(length_m)
        
I2C_BUS = 1
I2C_ADDRESS = 0x40

SCALE_FACTOR = 140.0
OFFSET = 32000.0

def crc8(data):
    # SFM3xxx CRC-8: polynomial 0x31, initial value 0x00.
    crc = 0x00

    for byte in data:
        crc ^= byte

        for _ in range(8):
            if crc & 0x80:
                crc = ((crc << 1) ^ 0x31) & 0xFF
            else:
                crc = (crc << 1) & 0xFF

    return crc


class SFM3000CRCError(RuntimeError):
    pass


class Flowmeter:
    def __init__(self, bus=I2C_BUS, address=I2C_ADDRESS, bus_factory=smbus2.SMBus, max_errors=5):
        self.bus_number = int(bus)
        self.address = int(address)
        self.bus_factory = bus_factory
        self.max_errors = max(1, int(max_errors))
        self.bus = None
        self.flow = 0.0
        self.sample_monotonic = None
        self.connected = False
        self.error_count = 0
        self.consecutive_errors = 0
        self.crc_error_count = 0
        self.reconnect_count = 0
        self.last_error = None
        self.serial_number = None
        self.article_number = None
        self.scale_factor = SCALE_FACTOR
        self.offset = OFFSET
        self._lock = threading.RLock()
        self._connect(query_identity=True)

    def _connect(self, query_identity=True):
        self._close_bus()
        self.bus = self.bus_factory(self.bus_number)
        try:
            if query_identity:
                try:
                    self.serial_number = self.read_u32(0x31AE, 0x31AF)
                    self.article_number = self.read_u32(0x31E3, 0x31E4)
                    scale = self.read_signed_word(0x30DE)
                    offset = self.read_signed_word(0x30DF)
                    if scale <= 0:
                        raise RuntimeError(f"SFM3000 invalid scale factor {scale}")
                    self.scale_factor = float(scale)
                    self.offset = float(offset)
                except Exception as error:
                    print(f"SFM3000 identity query failed; using defaults: {error}", flush=True)
            self.start_measurement()
        except Exception:
            self._close_bus()
            raise
        self.connected = True
        self.consecutive_errors = 0
        self.last_error = None
        print(
            f"SFM3000 connected: serial={self.serial_number}, article={self.article_number}, "
            f"scale={self.scale_factor:g}, offset={self.offset:g}",
            flush=True,
        )

    def _close_bus(self):
        bus, self.bus = self.bus, None
        if bus is not None:
            try:
                bus.close()
            except Exception:
                pass

    def write_command(self, command):
        msb = (command >> 8) & 0xFF
        lsb = command & 0xFF

        if self.bus is None:
            raise RuntimeError("SFM3000 I2C bus is closed")
        msg = i2c_msg.write(self.address, [msb, lsb])
        self.bus.i2c_rdwr(msg)

    def read_word(self):
        if self.bus is None:
            raise RuntimeError("SFM3000 I2C bus is closed")
        msg = i2c_msg.read(self.address, 3)
        self.bus.i2c_rdwr(msg)

        data = list(msg)

        msb = data[0]
        lsb = data[1]
        crc = data[2]

        if crc8(bytes([msb, lsb])) != crc:
            raise SFM3000CRCError(
                f"SFM3000 CRC mismatch: received 0x{crc:02x} for {msb:02x}{lsb:02x}"
            )

        return (msb << 8) | lsb

    def read_signed_word(self, command):
        self.write_command(command)
        time.sleep(0.001)
        value = self.read_word()
        return value - 0x10000 if value >= 0x8000 else value

    def read_u32(self, high_command, low_command):
        self.write_command(high_command)
        time.sleep(0.001)
        high = self.read_word()
        self.write_command(low_command)
        time.sleep(0.001)
        return (high << 16) | self.read_word()

    def start_measurement(self):
        last_error = None
        for i in range(5):
            try:
                self.write_command(0x1000)
                time.sleep(0.1)
                return
            except OSError as e:
                last_error = e
                print(f"SFM3000 start failed {i+1}/5: {e}", flush=True)
                time.sleep(0.2)
        raise RuntimeError("SFM3000 did not start") from last_error

    def step(self):
        with self._lock:
            try:
                raw = self.read_word()
                self.flow = (raw - self.offset) / self.scale_factor
                self.sample_monotonic = time.monotonic()
                self.connected = True
                self.consecutive_errors = 0
                self.last_error = None
            except Exception as error:
                self.error_count += 1
                self.consecutive_errors += 1
                self.last_error = str(error)
                if isinstance(error, SFM3000CRCError):
                    self.crc_error_count += 1
                if self.consecutive_errors >= self.max_errors:
                    self.connected = False
                    self.reconnect_count += 1
                    try:
                        self._connect(query_identity=False)
                        self.last_error = f"{error}; reconnected"
                    except Exception as reconnect_error:
                        self.last_error = f"{error}; reconnect failed: {reconnect_error}"
                raise

    def get_flow(self):
        with self._lock:
            return self.flow

    def get_sample(self):
        with self._lock:
            return self.flow, self.sample_monotonic

    def diagnostics(self):
        with self._lock:
            sample_age = (
                time.monotonic() - self.sample_monotonic
                if self.sample_monotonic is not None
                else None
            )
            return {
                "connected": self.connected,
                "sample_age_sec": sample_age,
                "error_count": self.error_count,
                "consecutive_errors": self.consecutive_errors,
                "crc_error_count": self.crc_error_count,
                "reconnect_count": self.reconnect_count,
                "last_error": self.last_error,
                "serial_number": self.serial_number,
                "article_number": self.article_number,
                "scale_factor": self.scale_factor,
                "offset": self.offset,
            }

    def close(self):
        with self._lock:
            self.connected = False
            self._close_bus()


class AerosolFlowmeter:
    """Cached SDP8xx pressure, temperature, and calibrated aerosol flow."""

    def __init__(self, bus=1, address=0x25, calibration_lpm_per_pa=0.15228426395939088):
        # Keep this optional hardware dependency out of normal startup/imports.
        from sensirion_i2c_driver import I2cConnection, LinuxI2cTransceiver
        from sensirion_i2c_sdp import SdpI2cDevice

        transceiver = LinuxI2cTransceiver(f"/dev/i2c-{int(bus)}")
        self.transceiver = transceiver
        connection = I2cConnection(transceiver)
        self.device = SdpI2cDevice(connection, slave_address=int(address))
        self.calibration = float(calibration_lpm_per_pa)
        self.lock = threading.Lock()
        self.io_lock = threading.Lock()
        self.pressure_pa = float("nan")
        self.temperature_c = float("nan")
        try:
            self.device.stop_continuous_measurement()
        except Exception:
            pass
        self.device.start_continuous_measurement_with_mass_flow_t_comp()
        time.sleep(0.01)
        self.step()

    def step(self):
        with self.io_lock:
            pressure, temperature = self.device.read_measurement()
        with self.lock:
            self.pressure_pa = float(pressure.pascal)
            self.temperature_c = float(temperature.degrees_celsius)

    def snapshot(self):
        with self.lock:
            pressure = self.pressure_pa
            temperature = self.temperature_c
        return self.calibration * pressure, pressure, temperature

    def read_pressure_samples(self, count=10, interval_sec=0.5, cancel_event=None):
        pressures = []
        for index in range(max(1, int(count))):
            if cancel_event is not None and cancel_event.is_set():
                raise RuntimeError("Aerosol calibration cancelled")
            self.step()
            _, pressure, _ = self.snapshot()
            pressures.append(pressure)
            if index + 1 < count:
                time.sleep(max(0.05, float(interval_sec)))
        return pressures

    def close(self):
        try:
            with self.io_lock:
                self.device.stop_continuous_measurement()
        except Exception:
            pass
        close = getattr(self.transceiver, "close", None)
        if close is not None:
            try:
                close()
            except Exception:
                pass


class PicoValve:
    def __init__(self, port="/dev/ttyACM0", baudrate=115200):
        self.ser = serial.Serial(port, baudrate, timeout=2)
        time.sleep(2)
        self.ser.reset_input_buffer()

    def command(self, cmd):
        self.ser.write((cmd + "\n").encode())
        return self.ser.readline().decode().strip()

    def on(self):
        return self.command("ON")

    def off(self):
        return self.command("OFF")

    def status(self):
        return self.command("STATUS")

    def close(self):
        self.off()
        self.ser.close()
        
class DacOut:
    def __init__(self, pin=18):
        self.sw = OutputDevice(pin, initial_value=0)

    def allow(self):
        self.sw.value = 1

    def block(self):
        self.sw.value = 0

    def close(self):
        self.block()
        self.sw.close()


class BlowerDAC:
    def __init__(self):
        self.dac = GP8403(
            i2c_addr=0x5F,
            bus=1
        )

        self.voltage = 0.0

        # test communication
        self.dac.set_dac_out_voltage(
            voltage=0,
            channel=1
        )

        print("GP8403 connected")

    def set_voltage(self, voltage):
        self.voltage = float(voltage)

        # limit 0–5V
        self.voltage = max(0, min(5, self.voltage))

        self.dac.set_dac_out_voltage(
            voltage=self.voltage,
            channel=1
        )

    def get_parameter(self):
        return self.voltage

    def close(self):
        self.set_voltage(0.0)
        close = getattr(self.dac, "close", None)
        if close is not None:
            close()

if __name__ == "__main__":
    valve = PicoValve()
    print("Turning valve ON...")
    print(valve.on())
    time.sleep(20)
    print("Valve status:", valve.status())
    print("Turning valve OFF...")
    print(valve.off())
    time.sleep(2)
    print("Valve status:", valve.status())
    valve.close()

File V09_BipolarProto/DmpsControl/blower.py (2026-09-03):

if __name__ == "__main__":
    from hardware import BlowerDAC, Flowmeter
    from tuning import lambda_pi_from_step
else:
    from .hardware import BlowerDAC, Flowmeter
    from .tuning import lambda_pi_from_step
from simple_pid import PID
import threading
import time
import math
from datetime import datetime



class FlowController:
    def __init__(self, flowmeter, blower, flow_lpm=10, kp=0.008, ki=0.015, kd=0.0):
        self.flowmeter = flowmeter
        self.blower = blower
        self.pid = PID(kp, ki, kd, setpoint=flow_lpm, auto_mode=False)
        self.pid.output_limits = (0, 5)
        self.running = False
        self.thread = None
        self._io_lock = threading.Lock()
        self._tuning_lock = threading.Lock()
        self._tuning = threading.Event()
        self._shutdown = threading.Event()
        self.flow_error_count = 0
        self.out = 2.5
        self.blower.set_voltage(self.out)
        self.pid.set_auto_mode(True, last_output=self.out)

    def setpoint(self, flow_lpm):
        with self._io_lock:
            self.pid.setpoint = flow_lpm
            if flow_lpm <= 0:
                self.out = 0.0
                self.pid.reset()
                self.blower.set_voltage(self.out)

    def start(self):
        if self.running:
            return
        self.running = True
        self.thread = threading.Thread(target=self.loop, daemon=True, name="sheath-flow-controller")
        self.thread.start()

    def stop(self, timeout=2.0):
        self.running = False
        if self.thread is not None and self.thread is not threading.current_thread():
            self.thread.join(timeout=timeout)

    def emergency_stop(self):
        self.running = False
        self._shutdown.set()
        self._tuning.set()
        with self._io_lock:
            self.pid.setpoint = 0.0
            self.pid.set_auto_mode(False)
            self.out = 0.0
            self.blower.set_voltage(0.0)

    def loop(self):
        while self.running:
            if self._tuning.is_set():
                time.sleep(0.05)
                continue
            try:
                with self._io_lock:
                    self.flowmeter.step()
                    raw = self.flowmeter.get_flow()
                    setpoint = float(self.pid.setpoint)
                    if setpoint <= 0:
                        self.out = 0.0
                    else:
                        self.out = self.pid(raw)
                    self.blower.set_voltage(self.out)
                    self.flow_error_count = 0
            except Exception as e:
                self.flow_error_count += 1
                print(f"Flowmeter error {self.flow_error_count}: {e}", flush=True)
                with self._io_lock:
                    self.out = 0.0
                    self.blower.set_voltage(self.out)
                print("Flowmeter failure: blower commanded to zero", flush=True)
                time.sleep(0.5)

            time.sleep(0.1)

    def pid_params(self):
        return {"Kp": self.pid.Kp, "Ki": self.pid.Ki, "Kd": self.pid.Kd}

    def set_pid_params(self, kp, ki, kd):
        values = (float(kp), float(ki), float(kd))
        if values[0] <= 0 or values[1] <= 0 or values[2] < 0:
            raise ValueError("PID gains must have Kp > 0, Ki > 0, and Kd >= 0")
        with self._io_lock:
            self.pid.tunings = values
            self.pid.reset()

    def run_step_tuning(self, config, cancel_event, sample_callback=None, progress_callback=None):
        """Temporarily own the real sheath loop and collect an open-loop DAC step."""
        if not isinstance(self.flowmeter, Flowmeter):
            raise RuntimeError("Tuning requires the real sheath SFM3000 Flowmeter")
        if not self.running:
            raise RuntimeError("Sheath flow controller is not running")
        low = float(config["output_low_v"])
        high = float(config["output_high_v"])
        settle = float(config["settle_sec"])
        step_sec = float(config["step_sec"])
        interval = float(config["sample_interval_sec"])
        if not (0.0 <= low < high <= 5.0) or high - low < 0.2:
            raise ValueError("Use 0..5 V outputs with a step of at least 0.2 V")
        if not 0.05 <= interval <= 5.0:
            raise ValueError("Sample interval must be 0.05..5 s")
        if settle < max(2.0, 5.0 * interval) or step_sec < max(2.0, 5.0 * interval):
            raise ValueError("Each plateau must allow at least five samples and last at least 2 s")
        if not self._tuning_lock.acquire(blocking=False):
            raise RuntimeError("Sheath PID tuning is already running")

        previous_setpoint = None
        previous_output = None
        samples = []
        self._tuning.set()
        try:
            with self._io_lock:
                previous_setpoint = float(self.pid.setpoint)
                previous_output = float(self.out)
                self.pid.set_auto_mode(False)
            started = time.monotonic()
            for phase, output, duration in (("low", low, settle), ("high", high, step_sec)):
                phase_started = time.monotonic()
                with self._io_lock:
                    self.blower.set_voltage(output)
                    self.out = output
                while time.monotonic() - phase_started < duration:
                    if cancel_event.is_set():
                        raise RuntimeError("Sheath PID tuning cancelled")
                    with self._io_lock:
                        self.flowmeter.step()
                        flow, sample_time = self.flowmeter.get_sample()
                    now = time.monotonic()
                    if sample_time is None or now - sample_time > max(0.5, 2.0 * interval):
                        raise RuntimeError("Stale sheath-flow sample during tuning")
                    row = {
                        "timestamp": datetime.now().isoformat(),
                        "elapsed_sec": now - started,
                        "step_elapsed_sec": now - phase_started if phase == "high" else 0.0,
                        "phase": phase,
                        "output_v": output,
                        "flow_lpm": float(flow),
                    }
                    samples.append(row)
                    if sample_callback:
                        sample_callback(row)
                    if not math.isfinite(row["flow_lpm"]):
                        raise RuntimeError("Nonfinite sheath-flow sample during tuning")
                    if not config["flow_min_lpm"] <= row["flow_lpm"] <= config["flow_max_lpm"]:
                        raise RuntimeError("Out-of-range sheath-flow sample during tuning")
                    if progress_callback:
                        total = settle + step_sec
                        progress_callback(min((now - started) / total, 0.99), phase, float(flow))
                    if cancel_event.wait(interval):
                        raise RuntimeError("Sheath PID tuning cancelled")
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

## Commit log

2026-01-16 Revise README structure to include Interactive BOM section and improve organization
2026-01-16 Refactor Interactive BOM section header and link for consistency
2026-01-16 Fix link in Interactive BOM section to include raw parameter for proper rendering
2026-01-16 Update Interactive BOM link to point to the correct URL for proper access
2026-03-08 Refactor code structure for improved readability and maintainability
    [OpetusSmpS.kicad_pcb, OpetusSmpS.kicad_sch]
2026-03-08 Fix typo in components per pcb link in README
2026-09-02 Add global controls loading functionality to the live inversion viewer
    - Introduced a button to load global controls on demand, improving initial load time.
    - Added a status message indicating that controls are loaded on demand.
    - Implemented a mechanism to load controls only when the corresponding tab is active.
    - Refactored the layout to include a new tab for global controls, enhancing user experience.
2026-09-03 Add Raspberry Pi GPIO dependency
2026-09-03 Release DMPS 0.2.1 with corrected scan settings
    [HV.py, hardware.py]
2026-09-15 Make Hauke DMA length configurable
2026-09-21 Add system health logging and diagnostics support
    - Introduce `dmps system-health` command to display recent system health logs.
    - Implement `log-system-health.py` to log CPU temperature, throttling status, memory usage, and Tailscale state.
    - Create `tdmps-health-log@.service` for managing the health logging service.
    - Update installation scripts to include the new health logging service.
    - Enhance `diagnose-reboot` command to include hardware watchdog policy and system health logger status.
    - Add unit tests for system health logging functionality.
2026-09-22 Refactor document_has_connected_clients to simplify session validation logic in gui_app.py and update corresponding test case in test_gui_settings.py
2026-09-25 Make heatmap ROIs selectable and clarify growth tracks
